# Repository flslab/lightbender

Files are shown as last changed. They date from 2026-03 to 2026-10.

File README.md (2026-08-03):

# LightBender
A LightBender is a form of FLS with an actuated rod as its lighting primitive.
A swarm of LightBenders illuminate graphics and animations visible to the naked eye.
When equipped with a cage, a LightBender facilitates safe, bare-hand interaction. 

Authors: Hamed Alimohammadzadeh(halimoha@usc.edu), Shuqin Zhu (shuqinzh@usc.edu), and Shahram Ghandeharizadeh (shahram@usc.edu)

Acknowledgments:  This research is supported in part by the National Science Foundation under Grant No. CMMI-2425754, CloudBank, and CloudLab. 

## Features

* Illuminations using a swarm of LightBenders, see below.
* Authoring tool in the form of a Blender add-on, see below and the instructions in the local [authoring](authoring/) directory.
* Bare-hand interaction with LightBenders, see below and the instructions in the local [Interaction](Interaction/) directory.
* Upload the video recording and log files generated by an illumination to a Google Drive for further analysis, see [orchestrator](orchestrator/) directory.
* Relative localization, see [relative-localization](https://github.com/flslab/fls-marker-localization.git).
* Log visualization tool, see [log visualizer web tool](https://flslab.github.io/fls-cf-log-visualizer/).

## Illumination
An artist may manipulate per-LED color and brightness, rod segment angles, and 3D position of one or more LightBenders to implement different visual effects. 

### LightBender Visual Effects

We support 7 visual effects today: Pulse, Color Cycle, Sparkle, Color Chase, Draw/Erase, Fold, and Fly-out/in.
These may be applied to arbitrary words and line drawings using the Blender add-on provided in the local [authoring](authoring/) directory.
Fold is a novel effect that utilizes the actuated rods of a swarm of LightBenders to transition lines to drawings and words.
The effects are highlighted by the following video clips:

- [Visual effects with ACM, LA, and NSF.](https://youtu.be/jwrJeGCwS_M)  
- [ACM Illumination.](https://youtu.be/oepzLSos4Xo)  
- [LA Illumination.](https://youtu.be/p_fx22tXJf8)  
- [NSF Illumination.](https://youtu.be/o2t5xLuE0Hw)

## Interaction
A cage provides safe bare-hand interactions with a LightBender, preventing users' hand and fingers from coming in contact with a LightBender's blades.  The provided software runs on the Raspberry Pi of a LightBender.  It enables the LightBender to monitor its own velocity to detect when a user engages or disegages.  This decentralized implementation enables multiple users to interact with different LightBenders simultaneously.  The following video shows Shahram and Shuqin interacting with a happy emoji.

- [Interaction with happy emoji.](https://youtu.be/_huysBvEuR4)
- [Vertical interaction with a LightBender.](https://youtu.be/ilh584zCPyQ)

Bare-hand interactions have diverse applications ranging from health-care to education and entertainment.  Our Blender add-on enables one or more users to adjust the position of LightBenders in an illumination using their bare-hands.  For a video demonstration, see [authoring](authoring/) directory.

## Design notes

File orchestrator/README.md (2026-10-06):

# Swarm Orchestrator

The Swarm Orchestrator manages the LightBender drone swarm. It handles executing SFL files, managing network communications, interacting with camera and radio nodes, downloading execution logs, and automatically uploading data after experiments.

## Setup

### 1. Install Dependencies
Ensure you have the required Python dependencies installed.
```bash
pip install -r requirements_orchestrator.txt
```

### 2. Configure the Swarm Manifest
The orchestrator relies on `swarm_manifest.yaml` to configure the network, drones, and mission files.

A sample template is provided as `swarm_manifest_sample.yaml`. To get started:
```bash
cp swarm_manifest_sample.yaml swarm_manifest.yaml
```

**Adjusting the manifest:**
Open `swarm_manifest.yaml` and update the following settings to match your environment:
- **`controller`**: Set your local machine's `ip`. You can define `mission_path` (e.g., `"SFL"`) and list out multiple `mission_files` to run sequentially.
- **`common.localizer_work_dir`**: Optional path to the marker-localization checkout on each drone; it defaults to `/home/fls/fls-marker-localization`. When that Git checkout exists, drone boot pulls it with a fast-forward-only update and runs its incremental high-rate release build before launching the controller.
- **`drones`**: Define the drones participating in the swarm. For each drone, make sure the `ip`, `uri`, hardware `type` (H or V), and `servo_offsets` match your actual hardware configurations.
- **`camera_node` / `radio_node`**: Provide the corresponding IP addresses and usernames for the remote nodes if you are using them for recording or CrazyRadio communication.
- **`marker_grid_node`**: Define the dedicated Raspberry Pi Zero W, its marker-grid checkout/virtual environment, grid JSON, UDP port, and GPIO levels. Set optional `hypergrid_tiles` to a list of `[i, j]` coordinates to light only those tiles' HyperGrid LEDs; omit it to light all HyperGrid tiles (an empty list lights none). The orchestrator validates and launches this node before it launches any drone. A drone that owns a MyGrid tile declares `marker_tile: [i, j]`.

The marker grid is deliberately not a drone peer. A drone requests a state
change over its existing ZMQ connection by sending
`{"id":"lb1","status":"MARKER_GRID_MODE","mode":"off"}`. The orchestrator
maps the drone ID to its manifest-owned tile and forwards an idempotent UDP
command to the grid. Modes are `blink`, `static`, and `off`; requests without a
drone target are reserved for orchestrator-wide lifecycle changes.
During cleanup, the orchestrator terminates the remote marker-grid controller;
its signal handler clears every LED channel before the process exits.

To test the physical marker grid without launching a mission, run
`python orchestrator.py --test-marker-grid`. The orchestrator turns on the
HyperGrid and all MyGrids, then prompts for Enter before turning each MyGrid
off and back on in snake order. Tile coordinates are `(i, j) = (x, y)`: tiles
with the same `i`, such as `(-1, -1)` and `(-1, 0)`, share an x row and are
adjacent along y. The controller is stopped when the test ends.

### 3. Uploader Setup
The orchestrator automatically uploads logs and experiment data (like recorded videos and drone logs) to Google Drive via the `uploader` module once a mission concludes.

Before running an experiment, you need to configure the uploader credentials:
1. A `.env.example` file is provided in the `uploader` directory. Copy it to create your `.env` file:
   ```bash
   cp uploader/.env.example uploader/.env
   ```
2. Edit `uploader/.env` and fill in:
   - `GOOGLE_CLIENT_SECRET`: Path to your downloaded OAuth client secret JSON file.
   - `GDRIVE_FOLDER_ID`: The ID of the shared Google Drive folder where data should be uploaded to.
   If you need to generate a new OAuth client secret JSON file, follow the instructions here: https://developers.google.com/workspace/guides/create-credentials

## Usage

Run the main script using Python. The orchestrator has a number of available execution modes.

```bash
python orchestrator.py [OPTIONS]
```

### Important Runtime Flags:
- **`--illumination`**: Run an illumination application mission.
- **`--interaction`**: Run an interaction application mission.
- **`--morphing`**: Run the mission with morphing algorithms enabled.
- **`--radio`**: Connect to drones over CrazyRadio (commands forwarded via the radio node).
- **`--ground`**: Perform a ground test without making the drones take off (useful for testing LED interactions or servos).
- **`--dark`**: Optimize camera parameters for recording in darkness.

### Control & Override Flags:
- **`--off`**: Cleanly power off / shut down all Raspberry Pis on the drones.
- **`--kill`**: Terminate the active Python controller processes on all drones.
- **`--skip-record`**: Run the mission without triggering the camera node.
- **`--record`**: Run the camera script strictly to record (no drone operation).
- **`--skip-confirm`**: Bypass manual confirmation prompts during the initialization sequence.

### Example Experiment

Running a standard illumination mission:
```bash
python orchestrator.py --illumination
```
When executed, the orchestrator will:
1. Parse the configurations and mission files from `swarm_manifest.yaml`.
2. Connect to the drones and issue restart commands.
3. Automatically launch the remote scripts and await "READY" payloads.
4. Prompt you (if not skipped) to launch the swarm.
5. Manage flight state logic and await "LANDED" confirmations.
6. Gather logs locally and trigger the `uploader` to save them seamlessly to Google Drive.

## Mock Blender Flow

To emulate an illumination launch without booting the real swarm, run:

```bash
python mock_orchestrator.py
```

This mock client connects to the Blender add-on's swarm monitor socket on `127.0.0.1:5598`, sends the same newline-delimited JSON status messages as the real orchestrator, and pauses before each message group so you can confirm the next step from the CLI.

Helpful flags:
- `--drone-id lb1 --drone-id lb2`: limit the mock run to specific drones.
- `--manifest path/to/swarm_manifest.yaml`: use a different manifest.
- `--message-delay 0.0`: send each group immediately with no spacing between messages.
- `--auto-cleanup-on-stop`: if Blender sends `stop`, automatically follow with `logs_fetched` and `all_stopped`.

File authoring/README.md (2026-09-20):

# LightBender Authoring

This directory contains the tools for designing, animating, and visualizing LightBender drone swarms. The primary authoring interface is a Blender add-on that enables an artist to place LightBenders in 3D space, animate LEDs and servos, and export an SFL (mission YAML) file for physical illumination using LightBenders and the orchestrator.  The add-on supports a novel edit mode that enables the artist to interact with the LightBenders and adjust their location using their bare hand. 

Authors: Hamed Alimohammadzadeh(halimoha@usc.edu), Shuqin Zhu (shuqinzh@usc.edu), and Shahram Ghandeharizadeh (shahram@usc.edu)

---

## Edit Mode Using Bare-Hand Interactions

We support bare-hand interactions with LightBenders to edit graphics.  Multiple users may adjust the position of LightBenders using their bare hand simultaneously.  Our implementation of the Blender add-on updates the data in real-time.  The following video shows the workflow of a bare-hand interaction in support of edit mode. 

- [Blender add-on in edit mode with bare-hand interactions.](https://youtu.be/_I6qcD0NoYM)

## LightBender Visual Effects

LightBender visual effects for different illuminations:

- [Visual effects with ACM, LA, and NSF.](https://youtu.be/jwrJeGCwS_M)  
- [ACM Illumination.](https://youtu.be/oepzLSos4Xo)  
- [LA Illumination.](https://youtu.be/p_fx22tXJf8)  
- [NSF Illumination.](https://youtu.be/o2t5xLuE0Hw)  

## Blender Add-On

LightBender Swarm Animator

**LightBender Swarm Animator** (`blender_addon.py`) is a Blender 3.0+ add-on located in `View3D > Sidebar > LightBender`. It provides a full GUI workflow for:

- **LightBender placement** — add Type H/V rods, semicircle, or ring light elements with correct geometry and LED strips
- **Generative layouts** — automatically place LightBenders along SVG strokes using Vertex First Greedy (VFG) or Set Cover (SC) placement algorithms
- **LED animation** — define LED pointers (split points + color expressions) and apply global color expressions
- **Global LED effects** — apply procedural animation presets (Static Color, Blinking, Sparkle, Rainbow Wheel, Color Chase, Pulse, Color Cycle) to all or selected LightBenders
- **Draw/Erase effect** — sequence or simultaneously animate LightBenders writing strokes, with per-drone direction control and keyframe reversal
- **Fold effect** — keyframe LightBenders unfolding from a straight lit state into their target pose
- **Fly-In/Fly-Out effect** — generate exploded-assembly fly-in sequences
- **Morph** — transition the swarm from the current SVG layout to a new SVG shape
- **Position errors & drift** — inject random positional noise or continuous drift for simulation realism
- **Stagger** — stagger LightBender positions based on camera perspective to avoid downwash
- **Live swarm monitoring** — real-time per-drone status and battery voltage in list or grid view with filtering
- **Export & launch** — write the full animation to YAML and optionally launch the orchestrator or an interactive bare-hand editing session directly

### Installing the Add-On

1. In Blender, go to **Edit > Preferences > Add-ons > Install…**, select `blender_addon.py`, and enable the **LightBender Swarm Animator** add-on.

2. The panel will appear in the **3D Viewport sidebar** under the **LightBender** tab (`N` key to open).

3. In **Edit > Preferences > Add-ons**, find **LightBender Swarm Animator** and set the **Repository Directory** to the absolute path of your local clone. The path is saved permanently in Blender's user preferences — you only need to set it once.

The Set Cover policy can use either the built-in branch-and-bound solver or
Gurobi. To use Gurobi, install `gurobipy` in the external Python environment
used by the add-on and configure a valid Gurobi license. Other placement
policies and the built-in solver do not import or require Gurobi at runtime.

---

## Panel Reference

The sidebar is organized into one root panel and five collapsible sub-panels.

---

### LightBender Controls

The root panel. Always visible.

#### Add LightBender

Select a **Light Element Type** from the drop-down, then click **Create**:

| Type | Description |
|---|---|
| **Type H (Rod)** | Two-segment rod. Segment 1 spans 0–180°, Segment 2 spans 180–360°. |
| **Type V (Rod)** | Two-segment rod rotated 90°. Segment 1 spans 90–270°, Segment 2 spans 270–450°. |
| **Semicircle H** | Single-segment arc, 0–180°. One servo. |
| **Semicircle V** | Single-segment arc, 90–270°. One servo. |
| **Ring** | Full circle, no servo actuation. |

When **Ring** is selected, a **Ring Radius** (m) field appears before the Create button.

Click **Delete All LightBenders** to clear all LightBenders and their associated components from the active viewport.

#### Selected LightBender Controls

These controls appear when a LightBender object (`lb*`) is the active selection.

**Servo Angles**

- **Angle 1** (or **Arc Angle** for Semicircle types) — servo 1 angle in degrees.
- **Angle 2** — servo 2 angle in degrees (hidden for Semicircle types).
- Ring types show a "No Actuation" label; servo fields are suppressed.

**LED Configuration**

- **Mode** — choose between two per-drone LED modes:
  - **Single Expression** — one Python formula evaluated per LED. Available variables: `i` (LED index), `t` (time in seconds), `N` (total number of LEDs), `math`, and `random`. Example: `[255, 255, 255] if i < t*10 else [0, 0, 0]`.
  - **Pointers** — define colored segments using a base color and a list of split-point pointers. Each pointer has a position value and a color expression; LEDs before a pointer inherit the previous segment's color.
    - **Base Color (Start)** — color expression applied before the first pointer.
    - **Pointers list** — add/remove pointers with `+`/`−`. Each row shows the split position and the color to the right of that split.

- **Test/Update LEDs** — re-evaluates all LED formulas and refreshes viewport colors immediately (useful after editing formulas without scrubbing the timeline).

---

### Generative Layouts

Automates swarm placement from an SVG file or recreates layouts and animations by importing YAML mission files.

At the very top of this panel, there is a shared **Swarm Manifest** path field. When specified, both the SVG Transform and Import Mission tools will use it to match drone IDs and resolve their hardware types.

#### Import Mission YAML

Recreates the LightBenders, servo angles, LED configurations (expressions or pointers), and keyframe animations from a previously exported YAML mission file.

| Field | Description |
|---|---|
| **Mission YAML** | Path to the source mission YAML file to import. |

Click **Import Mission** to parse the YAML and build the animation in the viewport. The button is disabled until a file is selected.

#### SVG Transform and Place

Reads an SVG shape and places LightBenders along the shape's strokes using available LightBenders in the manifest. If there are not enough LightBenders in the manifest, it will insert additional LightBenders labeld as extra. 

| Field | Description |
|---|---|
| **SVG File** | Path to the source SVG file. |
| **Max Width / Max Height** | Bounding box (m) to scale the SVG layout into. |
| **Center X / Center Z** | World-space coordinates for the layout center. |
| **Placement Policy** | **VFG** or **Set Cover** — algorithm used to place drones along the shape's strokes. |
| **Set Cover Solver** | Shown for Set Cover. Choose dependency-free **Built-in B&B** or the lexicographic **Gurobi** MIP backend. |
| **LED Color** | Python RGB list (e.g. `[255, 0, 0]`) applied to all placed drones. |

Click **Transform and Place** to run the placement. The button is disabled until an SVG file is selected.

---

### Automated Animations

Contains five keyframe-generation tools.

#### Morph

Transitions the swarm from its current SVG-based layout to a second shape.

| Field | Description |
|---|---|
| **Shape 2 SVG** | Path to the target SVG file. |
| **Hold 1 (s)** | Time to hold the initial shape before moving. |
| **Morph (s)** | Duration of the transition between shapes. |
| **Hold 2 (s)** | Time to hold the final shape after arriving. |

Click **Generate Morph** to insert keyframes.

#### Fold

Animates all selected LightBenders unfolding from a straight, fully-lit state into their current posed angles.

| Field | Description |
|---|---|
| **Fold Angle (deg)** | Servo-1 angle for the straight state (Servo 2 = Fold Angle + 180°). TYPE_V offsets this by 90°. |
| **Hold (s)** | Duration of the straight state before folding. |
| **Transition (s)** | Duration of the fold-in motion. |
| **Align** | Snap all LBs to the swarm centroid along the selected axis (X/Y/Z) during the straight state. |
| **Distribute** | Evenly space all LBs along the selected axis (X/Y/Z) during the straight state. |
| **Equalize Size** | Scale each LB's LED pointer range by its camera distance so all rods appear the same on-screen length. |
| **Resolve Overlaps** | After positioning, stretch LB positions along the selected axis until the minimum inter-LB gap equals **Min Spacing**. |
| **Min Spacing (m)** | Minimum allowed distance between any two LBs when overlap resolution is active. |

Click **Generate Fold** to write keyframes; **Trash** icon clears them.

#### Draw/Erase

Sequences LightBenders to illuminate progressively, simulating a stroke being drawn and then erased.

**Groups list** — each group represents one stroke or letter. Groups can be Sequential (drawn one after the other) or Simultaneous (drawn in parallel). Use `+`/`−` to add/remove groups; click a group to manage its members.

**LightBenders in \<group\>** — ordered list of drones assigned to the active group. Use `+`/`−` to add/remove drones (adds the current viewport selection); arrow buttons reorder them.

**Settings:**

| Field | Description |
|---|---|
| **Draw Speed (LEDs/s)** | Rate at which LEDs illuminate during the draw pass. |
| **Erase Speed (LEDs/s)** | Rate at which LEDs turn off during the erase pass. |
| **Hold Time (s)** | Pause between the end of draw and the start of erase. |
| **Overlap Next (%)** | How much the next group's draw begins before the current group finishes (0 = fully sequential, 100 = fully overlapping). |
| **Draw RGB** | Color used during the draw pass (Python RGB list). |
| **Erase RGB** | Color used during the erase pass / background color (Python RGB list). |

Click **Generate Draw/Erase** to write keyframes; **Trash** icon clears them.

#### Fly-In / Fly-Out

Generates an exploded-assembly animation: drones fly in from off-screen positions to their targets, hold, then fly back out.

| Field | Description |
|---|---|
| **Ref Distance (m)** | Distance of the explosion reference point behind the centroid. |
| **Min/Max X, Y, Z (m)** | World-space bounding box from which start positions are sampled. |
| **Outward Duration (s)** | Time for drones to travel from their targets to the exploded positions. |
| **Hold Duration (s)** | Time drones pause at the exploded positions. |
| **Inward Duration (s)** | Time for drones to fly from the exploded positions back to their targets. |

Click **Generate Fly-In/Fly-Out** to write keyframes; **Trash** icon clears them.

#### Flight Attitude

Generates yaw-relative roll and pitch for the selected LightBenders from their
animated positions. The operator estimates acceleration over the position-keyed
frame range, smooths it, and writes per-frame roll/pitch keys while preserving
existing yaw animation.

| Field | Description |
|---|---|
| **Max Tilt** | Maximum combined roll/pitch angle produced by horizontal acceleration. |
| **Smoothing** | Number of frames on either side used to smooth acceleration and braking. Higher values produce slower, softer banking. |

Click **Apply to Selected** after selecting one or more position-animated
LightBenders. Applying replaces any existing roll and pitch curves; location
and yaw keys are left unchanged.

---

### Global LED Effects

Applies a procedural LED animation preset to all selected (or all) LightBenders in the scene.

**Preset** — choose from seven animation presets:

| Preset | Description |
|---|---|
| **Static Color** | Single, unchanging color. |
| **Global Blinking** | All LEDs cycle through the color list simultaneously. |
| **Random Sparkle** | Each LED randomly flickers independently. Controlled by **Sparkle Threshold**. |
| **Rainbow Wheel** | A moving rainbow gradient sweeps across LEDs over time. |
| **Color Chase** | A moving block of color travels along the LED strip. |
| **Pulse** | Brightness smoothly pulses in and out. |
| **Color Cycle** | Smoothly blends between two colors using a sin/cos oscillation. |

**Color list** — add/remove colors with `+`/`−`. Click **Load Preset Colors** to populate the list with sensible defaults for the selected preset.

| Field | Description |
|---|---|
| **Speed Multiplier** | Scales the animation speed for all presets. |
| **Sparkle Threshold** | (Sparkle only) Probability above which a LED shows the sparkle color. 0 = always on, 1 = never. |

Click **Apply to Selected** to write the expression only to the selected LightBenders, or **Apply to All** to target every LightBender in the scene.

---

### Physics & Simulation

Injects positional noise and staggers LightBender positions based on camera perspective to avoid downwash and overlaps.

#### Error & Drift Simulators

**Static Error (YZ Plane)**

Randomly offsets each LightBender to simulate real-world positioning inaccuracy.

| Field | Description |
|---|---|
| **Error Distance (m)** | Maximum random offset applied to each drone. |

Click **Apply Static Error** to offset positions; **Reset Static** to undo.

**Dynamic Drift (XYZ)**

Applies a smooth, sinusoidal drift to each LightBender's position over time, simulating hovering instability.

| Field | Description |
|---|---|
| **Max Drift XY (m)** | Maximum drift amplitude in the X and Y axes. |
| **Max Drift Z (m)** | Maximum drift amplitude in the Z axis. |
| **Wave Scale (Slower=Higher)** | Noise frequency scale; higher values produce slower, wider drift. |

Click **Apply Drift** to generate drift keyframes; **Reset Drift** to remove them.

#### Stagger

Resolves downwash and overlap conflicts by shifting LightBenders toward or away from the camera.

| Field | Description |
|---|---|
| **Overlap Threshold (m)** | Distance below which two drones are considered overlapping. |
| **Downwash Threshold (m)** | Horizontal distance below which a drone is in the downwash of an upper drone. |
| **Selection Method** | Algorithm for choosing which Lightbenders to stagger: **Greedy Max Degree**, **Greedy Top Z**, **Greedy Bottom Z**, **Brute Force**, or **Random**. |
| **Resolution Order** | Priority for resolving conflicts: **Max Degree**, **Top Z**, **Bottom Z**, or **Random**. |
| **Trajectory Type** | **Line of Sight** — move along the camera ray; **Global** — move along the global centroid. |
| **Move Direction** | **Away** from camera, **Towards** camera, or **Hybrid** (choose the direction that minimizes distance). |

Click **Stagger** to apply; **Reset Stagger** to restore original positions.

---

### Mission Export

Writes the animation to an SFL (YAML) file and optionally launches the orchestrator.

#### Export Config

| Field | Description |
|---|---|
| **Mission Name** | Base name used for the output SFL file (defaults to the Blender scene name). |
| **Dark Room** | Enable dark-room mode in the generated mission. |

#### Mode

Toggle between two export/illuminate modes:

**Illumination** 

| Field | Description |
|---|---|
| **Export Keyframes Only** | When enabled, only keyframe times are exported (variable `dt` per waypoint). When disabled, waypoints are sampled at a fixed rate. |
| **Export Rate (Hz)** | Sampling frequency when not in keyframe-only mode. |

Buttons:
- **Export YAML** — write the mission file to `orchestrator/SFL/<mission_name>.yaml`.
- **Illuminate** — export and immediately launch the orchestrator in a new terminal tab.
- **Confirm Launch** — enabled once all drones report `ready`; arms the swarm and begins the mission.
- **Stop** — commands all drones to land and waits for confirmation.

**Interaction**

| Field | Description |
|---|---|
| **S_D (mm/s)** | Speed threshold exported as `delta_v` (m/s) in the interaction YAML. |
| **Grace Time (s)** | Delay before the interaction controller begins accepting commands. |
| **Interaction Duration (s)** | Maximum duration of the interactive editing session. |

Buttons mirror Illumination mode, plus:
- **Edit** — opens a bare-hand editing session.
- **Finish Edit** — closes the editing session and returns drones to hover.

#### LightBender Status

Live swarm monitor, nested inside Mission Export. Updated in real time while the orchestrator is running.

**View Mode** — switch between **List** and **Grid** displays:

- **List** — shows all drones in a scrollable list with ID, status, and battery voltage. Filter controls:
  - **Status filter** — show All, Idle, Booting, Ready, or Landed drones.
  - **Voltage filter** — show All, Charged (≥ threshold), or Discharged (< threshold) drones.
  - **Battery Threshold (V)** — voltage cutoff for the charged/discharged filter (default 3.9 V).
  - Clicking a list entry selects the corresponding LightBender object in the 3D viewport.

- **Grid** — compact tile view with one button per drone labeled with its numeric ID. Tile color indicates status: gray = idle, yellow = booting, green = ready, blue = landed, red = error. Clicking a tile selects the drone in the 3D viewport.

---

## LB Author, CLI End-to-End Pipeline

For users who want to run the full authoring pipeline from the command line without using the graphical interface, the `lb_author.sh` script automates the complete flow from SVG parsing to spatial staggering and orchestrator invocation.

### Pipeline Steps

The script runs the following steps sequentially, ensuring the input file of each script is available before proceeding:
1. **Transform (`transform.py`)**: Converts an SVG file into a scaled 3D graph.
2. **Place (`place.py`)**: Maps the 3D graph onto a tentative layout of LightBenders.
3. **Stagger/Deconflict (`deconflict.py`)**: Checks for overlap and downwash conflicts and repositions drones to resolve them.
4. **Convert to SFL (`convert_to_mission.py`)**: Converts the staggered layout into an SFL mission file.
5. **Orchestrator (`orchestrator.py`)**: (Optional) Triggers the swarm orchestrator to illuminate the deconflicted mission layout.

### Setup Python Virtual Environment

If you have not already, go to the lightbender/ directory and create a Python virtual environment:

```bash
cd lightbender/
python3 -m venv env
source env/bin/activate
pip install -r authoring/requirements.txt
```

After the first time you only need to activate the virtual environment:

```bash
source env/bin/activate
```

### Usage

```bash
bash authoring/lb_author.sh [options] <input_file.svg>
```

#### Options

- `--no-viz`: Disables all step-by-step graphical 2D and 3D visualizers (e.g., matplotlib popups), allowing the entire script to run silently in headless/CLI environments.
- `--illuminate`: Automatically triggers the swarm orchestrator (`orchestrator.py`) at the end of the pipeline to launch and execute the generated mission layout.

#### Examples
To run the complete pipeline with visualizers:
```bash
bash authoring/lb_author.sh authoring/svg/s.svg
```
**Note:** To proceed to the next step, you need to close the plot windows.

To run the complete pipeline silently without visualizers:
```bash
bash authoring/lb_author.sh --no-viz authoring/svg/s.svg
```

To run the pipeline and immediately launch the orchestrator:
```bash
bash authoring/lb_author.sh --illuminate authoring/svg/s.svg
```

Optianly you can visualize the final SFL file using the following command:
```bash
python analysis/rmse_all.py --yaml orchestrator/SFL/lb_author_mission.yaml --lit-only
```

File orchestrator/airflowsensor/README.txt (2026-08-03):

This is Version 0 of the software for airflow sensor.  The python file in this directory is a standalone software executed on a RPi.  

Hardware:  
- Manufacturer:  Sensirion AG
- Model Number:  SEK-SDP31
- Description:   Digital Pressure Sensor Evaluation Kit.
- URL:  https://www.digikey.com/en/products/detail/sensirion-ag/SEK-SDP31/16517716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

3D Printed Parts: 
- Mounting of the airflow sensor to the rod for conducting experiments:
  * 3D printable files are Flow_element_grip.3mf and Rod_grip.3mf
  * 3D fusion files are FlowElement_grip.f3d - unfortunately, the fusion file for the other one is lost. 
- Prior to the arrival of the sensor, we 3D printed the part in order to setup the experiments with LightBenders.  The AutoCAD Fusion version of these files is ./

Software:  Custom built python at USC.

Requirements:
1. Enable I2C on RPi by running sudo raspi-config in the terminal.  Navigate to Interface Options, select I2C, choose Yes to enable it and automatically load kernel modules, and then reboot the system.  
2. Update ../orchestrator.py with the updated logic in ./orchestrator.py. 
3. Copy the manifest file (./swarm_manifest_sample.yaml) that describes the airflow sensor node in the Orchestrator directory.  
4. Run the updated Orchestrator with the additional flag, using the following command:  Python3 orchestrator.py --illumination --sensor

Output:
1. The revised Orchestrator generates log records based on Experiments 1 to 4 in the Google Slide. 

Experiments conducted using this software in the context of four different experiments are available in the following Google Slide:  https://docs.google.com/presentation/d/1wRDwtCE3NHDeBA4fOQYP56STGkDCzMYEMwvgELqPWFg/edit?usp=sharing

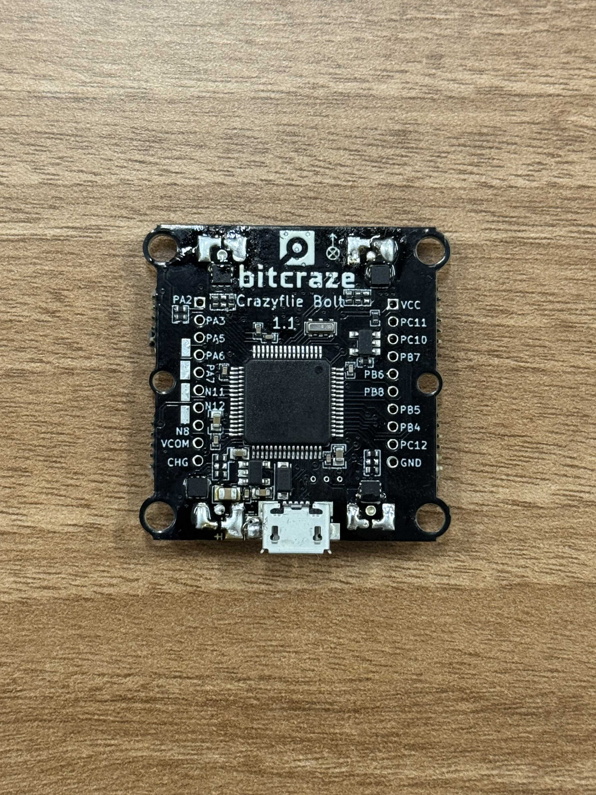
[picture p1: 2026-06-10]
docs/img/fc_down.jpeg

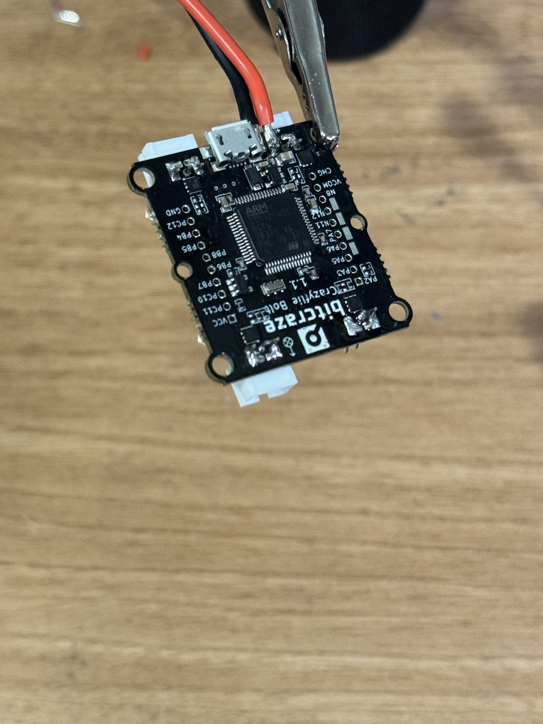
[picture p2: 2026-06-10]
docs/img/fc_power.jpeg

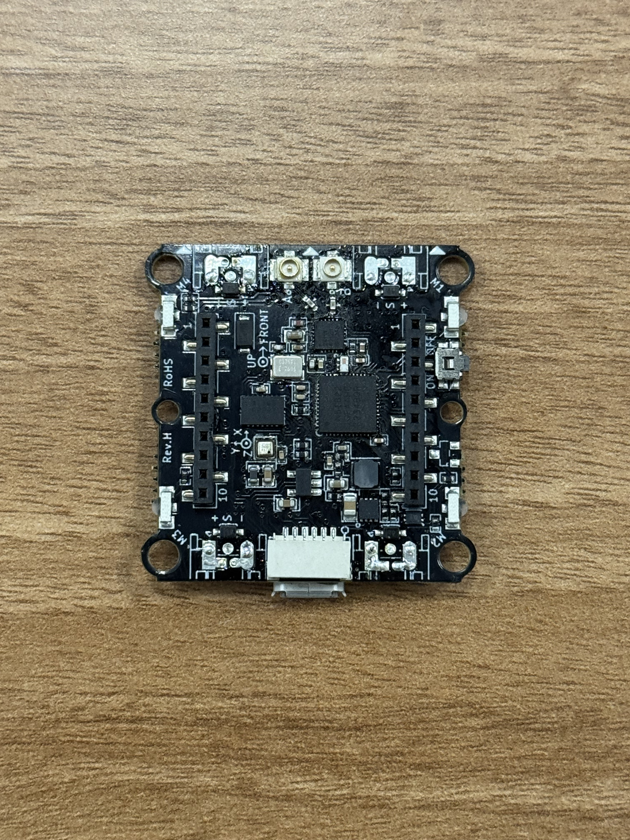
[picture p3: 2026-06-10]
docs/img/fc_up.jpeg

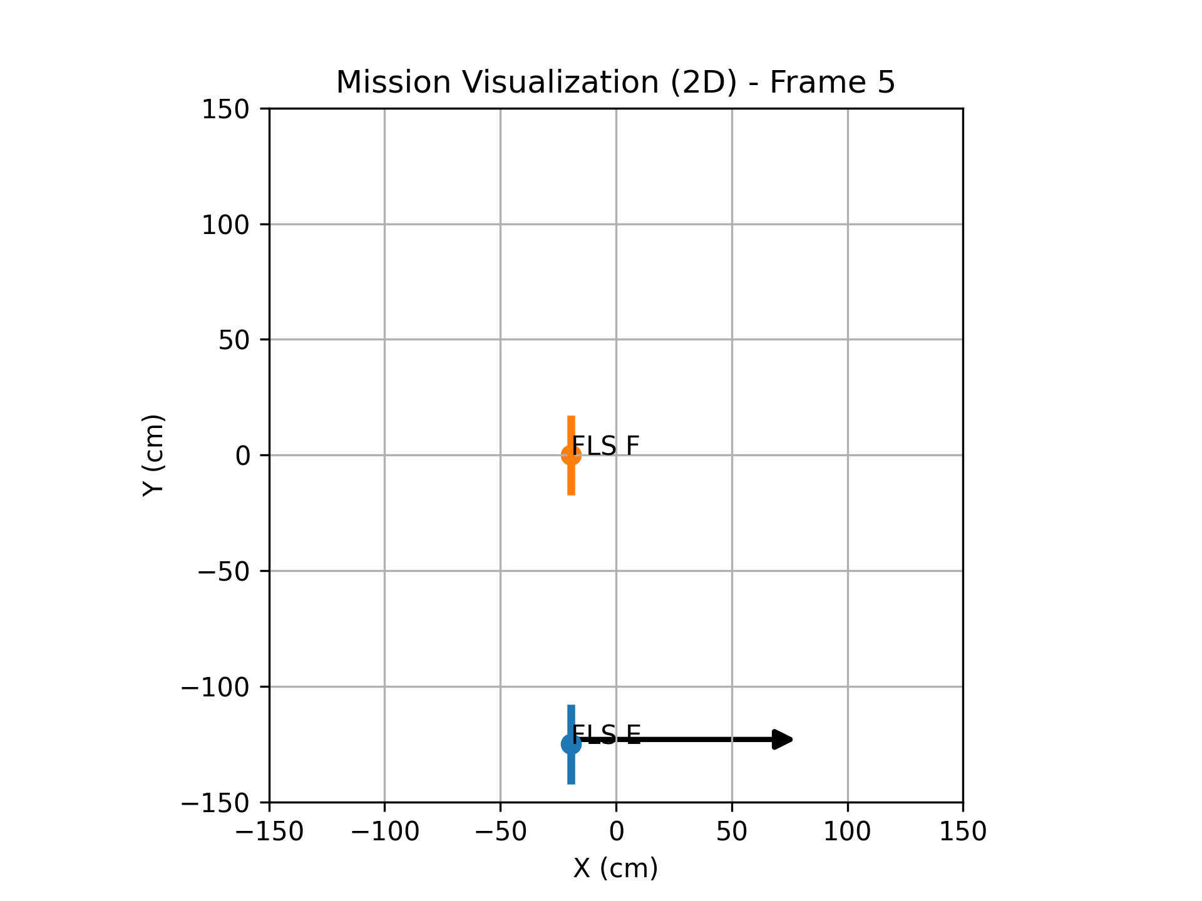
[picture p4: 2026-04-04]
morphing-orchestrator/mission_visualizations/mission_frame_5.png

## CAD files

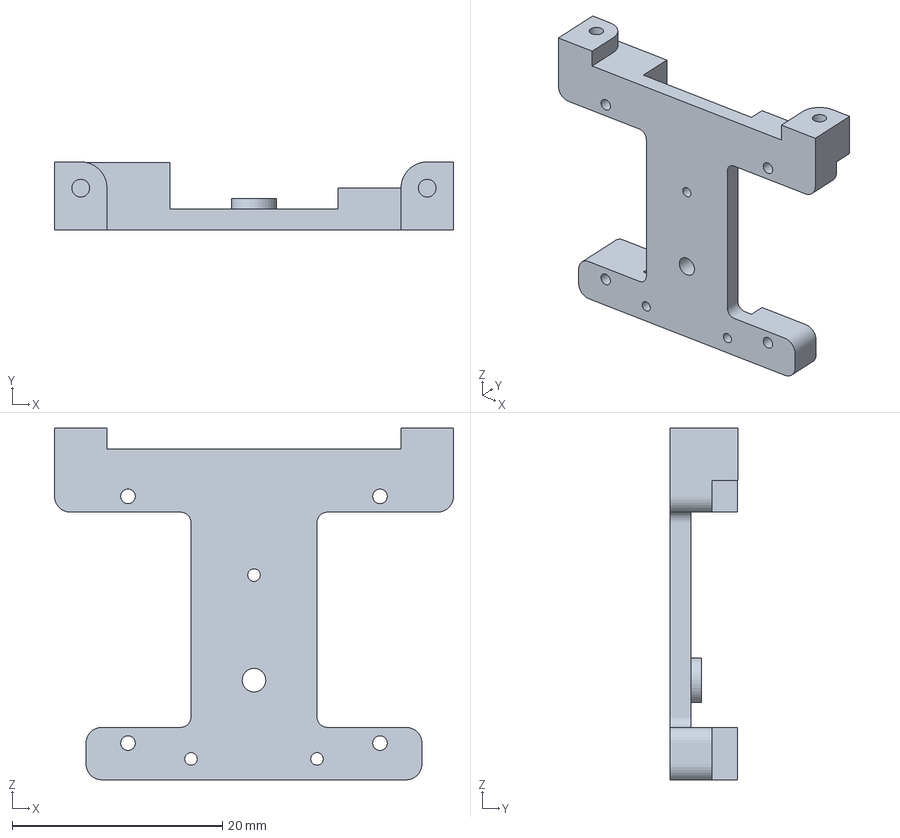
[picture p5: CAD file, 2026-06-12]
3d/linear/servo_case.3mf
38.0 x 6.50 x 33.5 mm

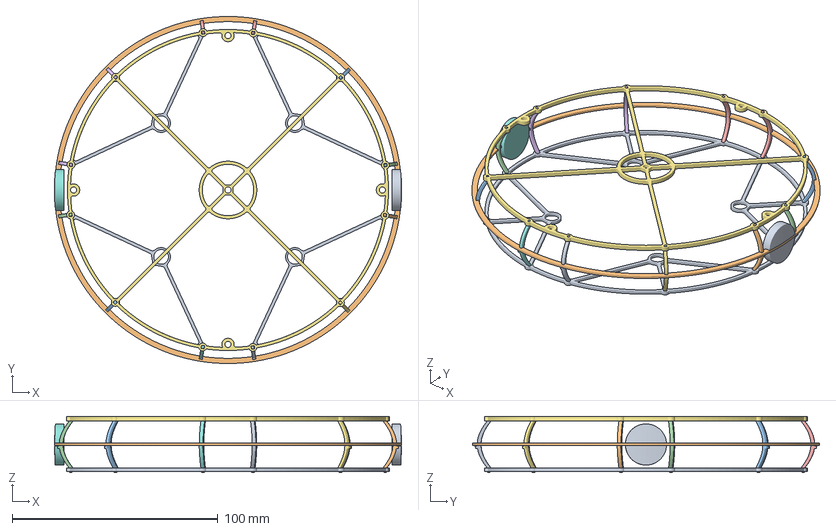
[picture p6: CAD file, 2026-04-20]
Interaction/Cage_Design/Crazyflie_Interaction_Cage.3mf
168.8 x 168.6 x 27.4 mm

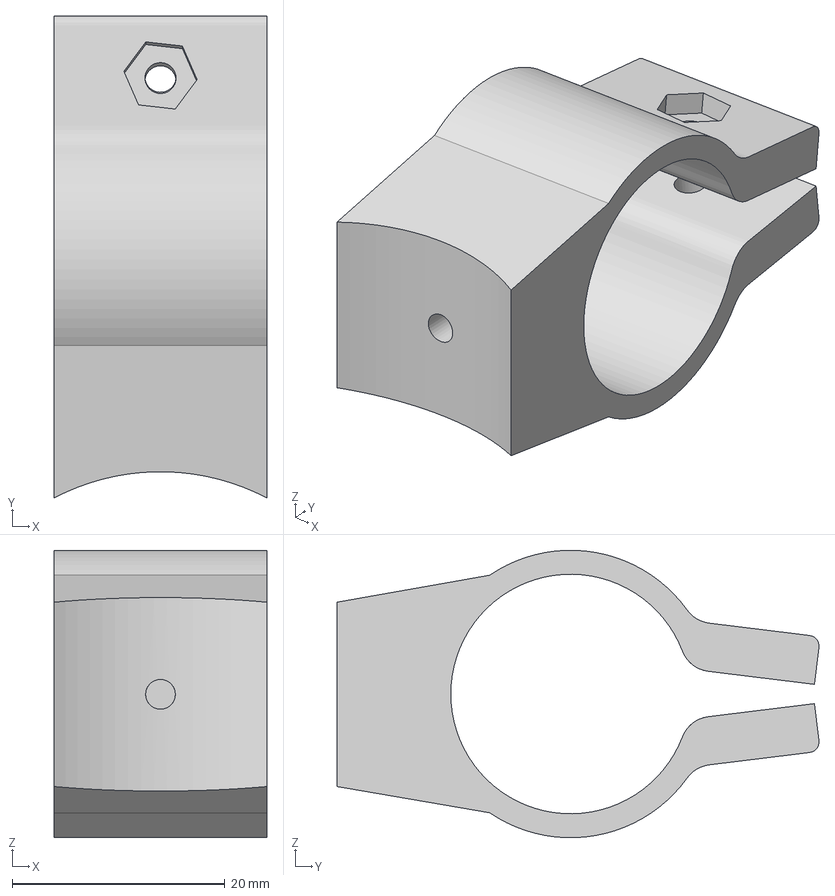
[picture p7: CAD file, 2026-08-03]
orchestrator/airflowsensor/Flow_element_grip.3mf
20.0 x 45.3 x 27.0 mm

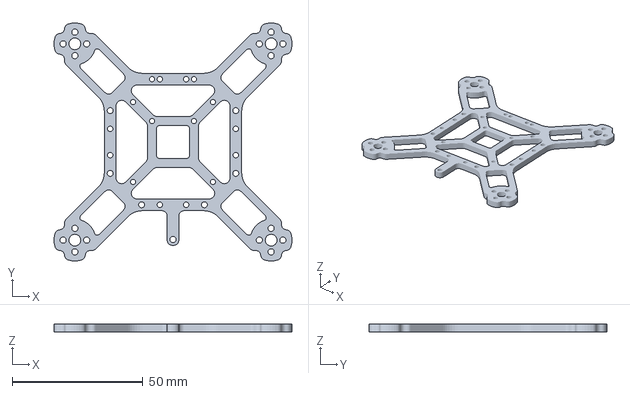
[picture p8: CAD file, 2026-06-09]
3d/linear/frame.3mf
91.0 x 91.0 x 3.00 mm

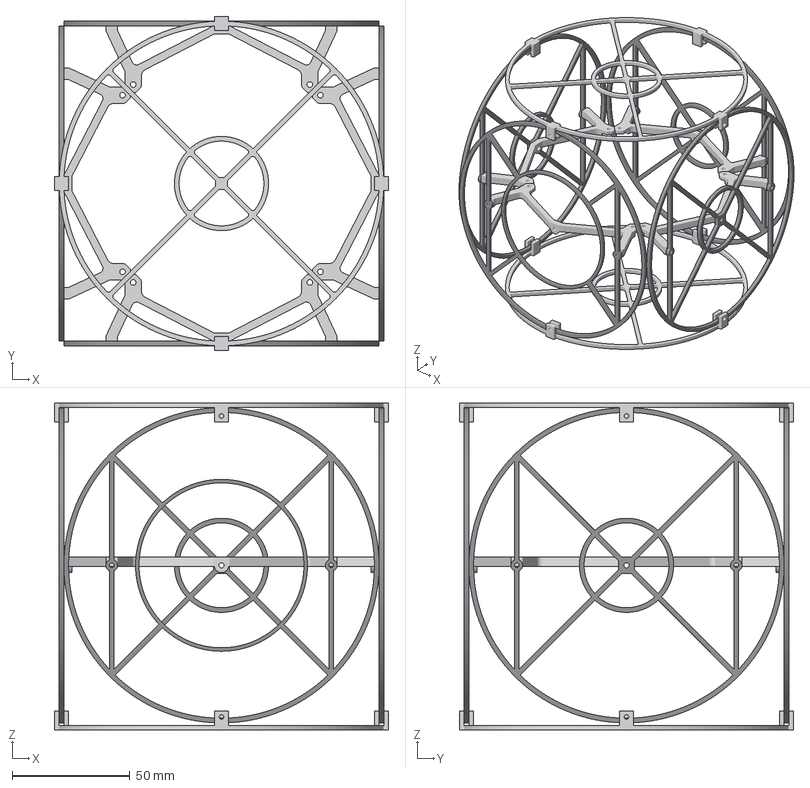
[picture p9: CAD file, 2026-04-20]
Interaction/Cage_Design/LightBender_Interaction_Cage.3mf
141.8 x 141.8 x 138.8 mm

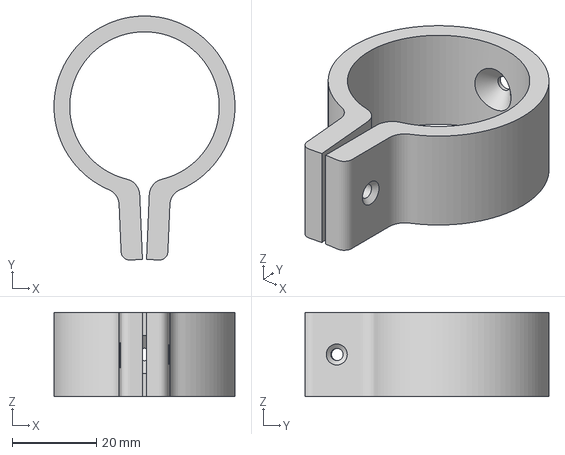
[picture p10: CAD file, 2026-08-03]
orchestrator/airflowsensor/Rod_grip.3mf
43.0 x 57.9 x 20.0 mm

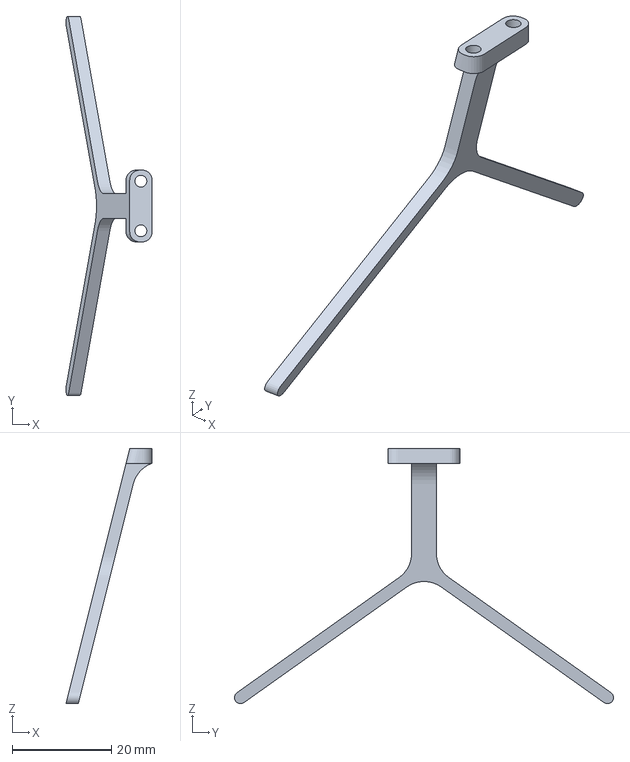
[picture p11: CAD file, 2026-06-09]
3d/linear/landing_gear.3mf
17.4 x 76.4 x 51.5 mm

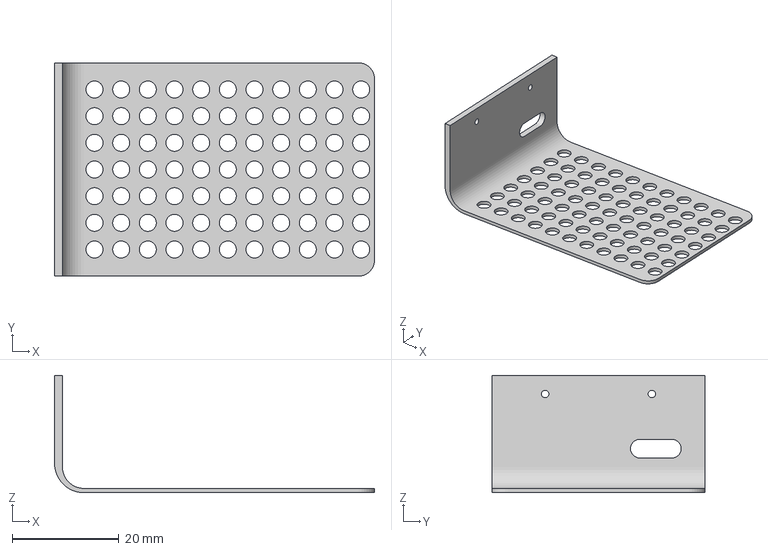
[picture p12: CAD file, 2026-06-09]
3d/linear/rpi_cover.3mf
60.0 x 40.0 x 22.0 mm

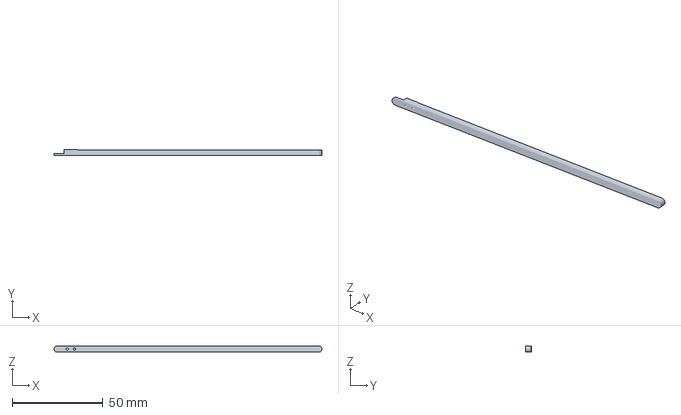
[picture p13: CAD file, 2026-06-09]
3d/linear/tube_segment.3mf
147.5 x 3.20 x 3.50 mm

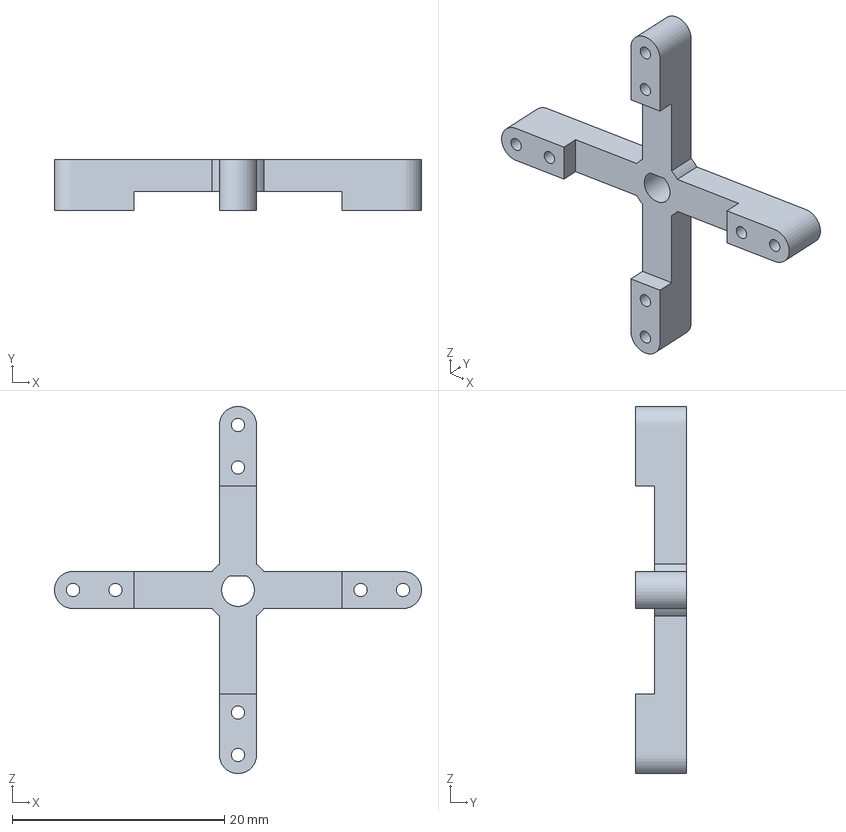
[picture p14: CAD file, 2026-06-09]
3d/linear/tube_joint.3mf
34.6 x 4.80 x 34.6 mm

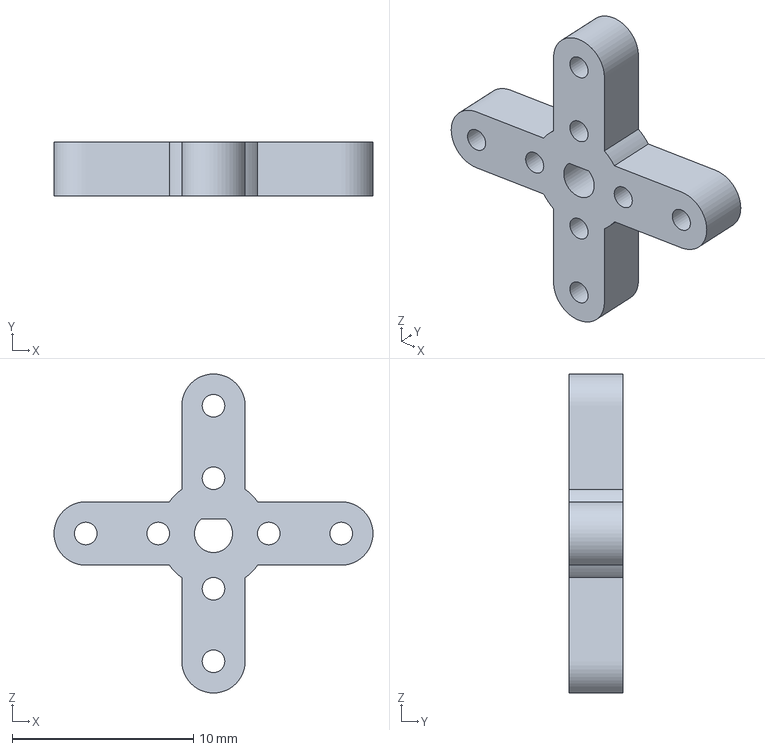
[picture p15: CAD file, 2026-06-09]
3d/linear/rod_joint.3mf
17.6 x 3.00 x 17.6 mm

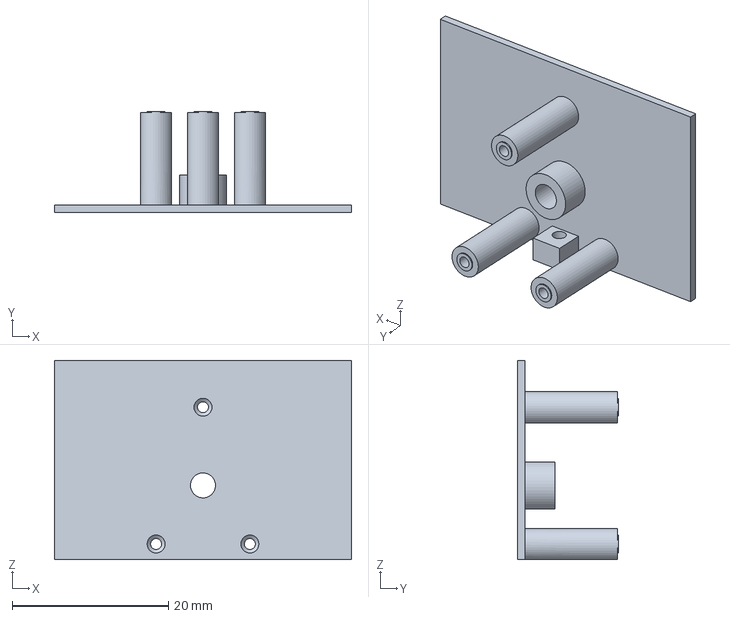
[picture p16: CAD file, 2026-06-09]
3d/linear/gearbox_case.3mf
38.0 x 12.9 x 25.5 mm

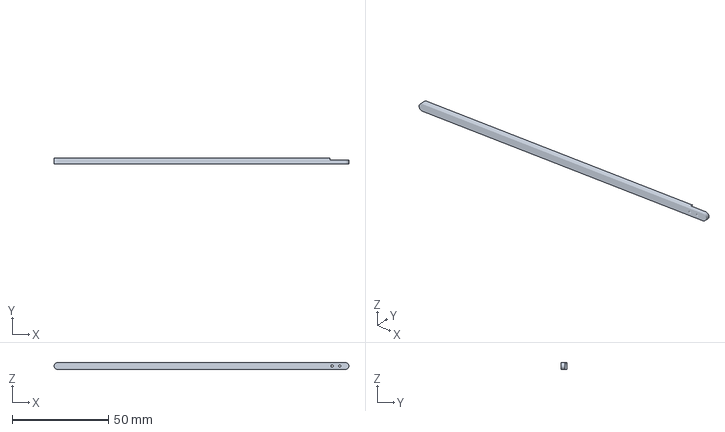
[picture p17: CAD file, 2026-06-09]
3d/linear/rod_segment.3mf
153.5 x 3.00 x 3.50 mm

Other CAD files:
orchestrator/airflowsensor/FlowElement_grip.f3d

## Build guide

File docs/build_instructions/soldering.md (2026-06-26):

# Soldering and Assembling

Required tools:

1. Soldering iron
2. Screwdriver set
3. Wire cutters and strippers
4. Pliers
5. Desoldering wick

Required parts:

1. Motors x 4
2. ESC x 1
3. CF Bolt Flight controller x 1
4. Power wires x 1
5. Capacitor x 1
6. Mulex wire with male connector x 1
7. Mulex wire with female connector x 1
8. Servos x 2
9. LED strips
10. Magnet wires
11. Power regulator x 1
12. Raspberry Pi Baseboard x 1

## Prepration:

Step 1: Unbox the motors and screw them to the frame. Use the 5mm screws (the meduim size in the package).
When mounting the motors, make sure the wires from the motor are facing towards the center of the frame.
Cut the wires from motor to desired length.

Step 2: Cut the mulex wires as shown below.

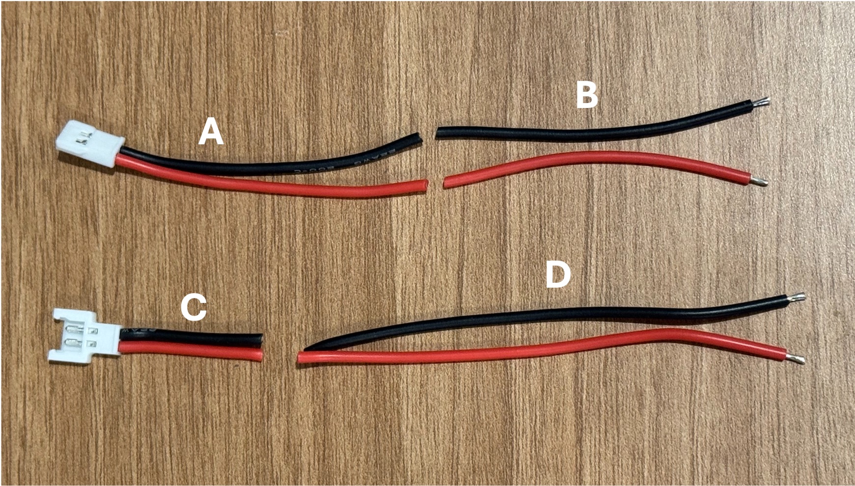
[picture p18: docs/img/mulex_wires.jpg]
Cutting the mulex wires.


Step 3: Cut the XT30 power wires from the ESC to desired length(around 2 inch or 5 cm).

Step 4: Cut 4 peice of wires for motor signal wires (around 1.5-2 inch or 4-5 cm).

Step 5: Cut 3 pieces of wires making a USB cable (around 2.5 inch or 6 cm)

Step 6: Cut the connectors of the servos.

Step 7: Cut 5 pieces of magnet wires around 20 cm each.

Step 8: Strip the tip of all prepared wires in Steps 1 to 7 and put solder on them. For magnet wires use a soldering iron and solder to melt the coating.

Step 9: Cut two strips of 24 and 26 LEDs from LED strip. When cutting make sure you cut from the lines between the LEDs such that each LED has 3 connection points. One ground (GND), one data (DI), and one power (VCC/5V).

Step 10: Remove the 3-pin connectors from the flight controller. First remove the plastic housing gently using a plier, and then remove the pins using a soldering iron.

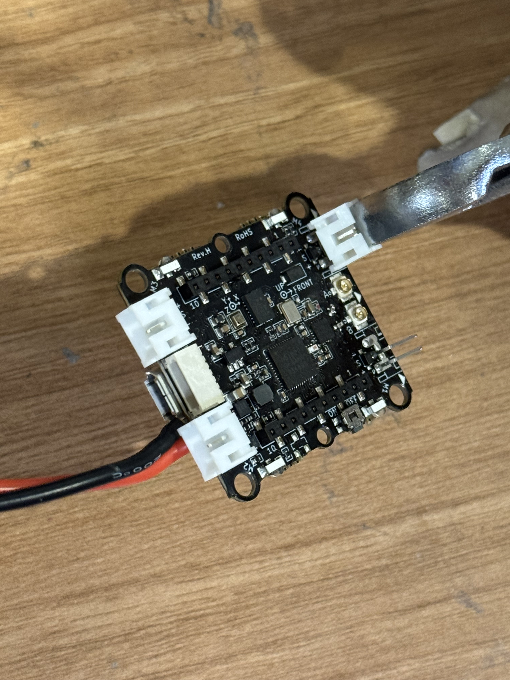
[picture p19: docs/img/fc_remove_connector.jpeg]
Removing plastic housings.


Step 11: Desolder the power wires from the FC.

## ESC and FC Assembly

Step 12: Solder wire B to the FC.

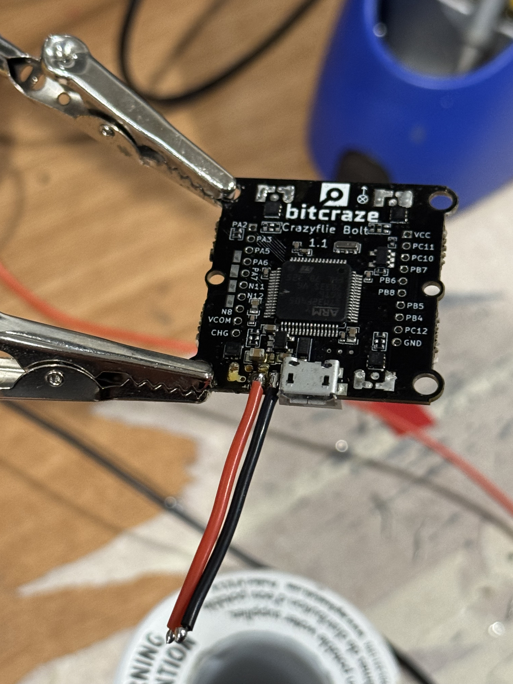
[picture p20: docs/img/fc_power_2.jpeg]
Soldering power cables to the FC.


Step 13: Solder the capacitor and XT30 power wires to the bottom side of the ESC.

Step 14: Solder the mulex wire with the male connector (wire A) and the other ends of wire B to the top side of the ESC.

Step 15: Mount the ESC on the frame using the 8mm screws. The ESC should be mounted on the opposite side of the frame from the motors.

Step 16: Solder the motor signal wires from step 4 to the FC. Make sure you connect the wires to the top side of the FC.

Step 17: Pass the motor signal wires through the frame and solder them to the corresponding motor posts on the ESC. Refer to the image below.

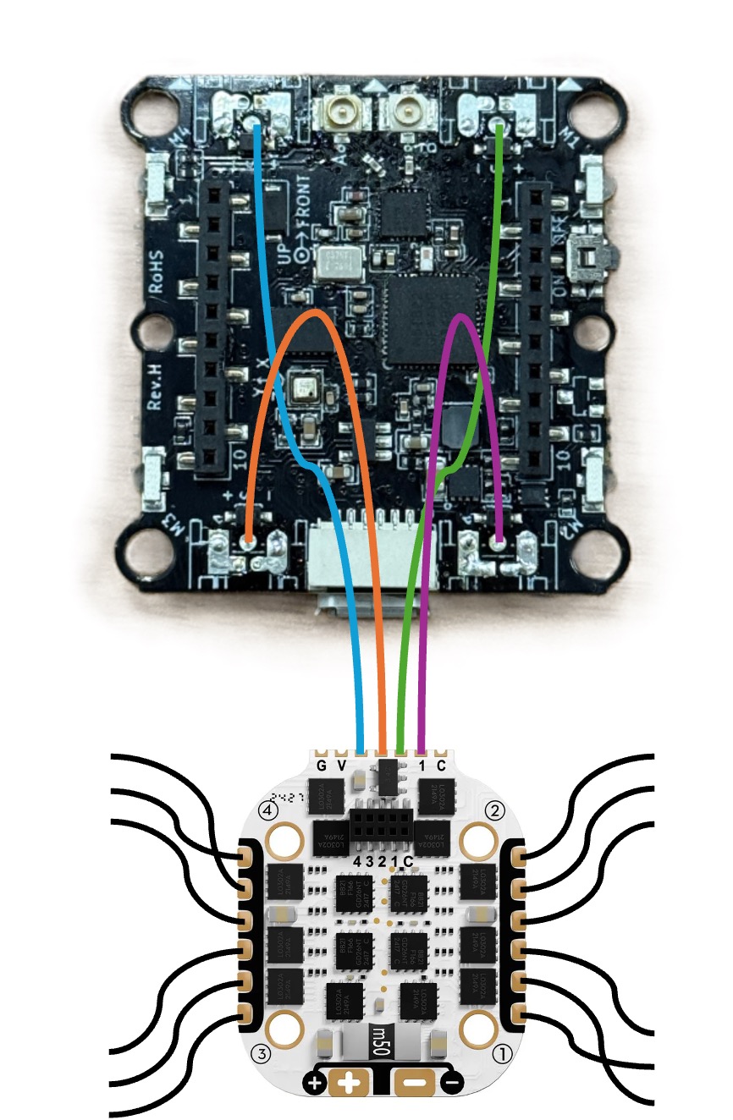
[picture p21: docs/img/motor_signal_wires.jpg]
Wring motors.


Step 18: Connect the FC anttena to the coaxical connector labeled as A on the top of the flight controller. Mount the flight controller on the frame using the 8mm screws and rubber balls.

Step 19: Solder motor wires from the motors to the ESC. Refer to the image above to see the correct wire ordering for each motor.

Finally your frame should look like this:

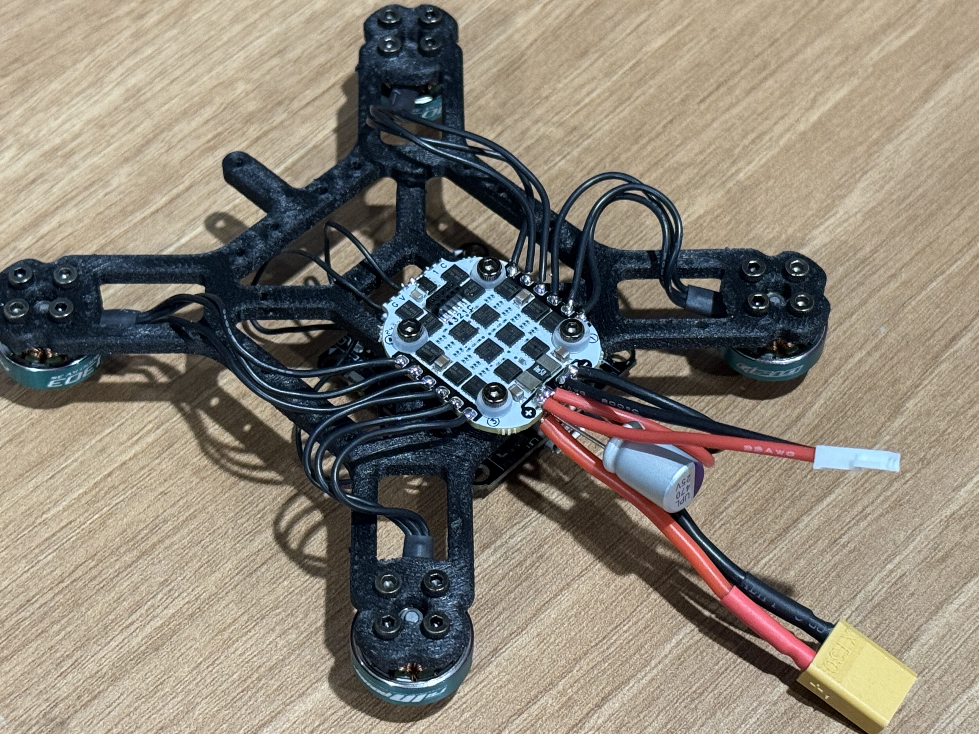
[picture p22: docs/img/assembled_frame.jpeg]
Assembled frame.


## RPi Baseboard and Power Assembly

Step 20: Solder the red wire of C to the VIN pin of the power Regualtor and red wire D to the OUT pin of the power Regualtor. Solder the black wires to the GND pins of the power Regualtor.

Step 21: Solder the power wires of the servo the the OUT and GND of the power regulator. Connect red to OUT and brown/black to GND.

Step 22: Solder the other ends of wire D to the RPi baseboard 5V and GND pins.

Step 23: Solder the yellow signal wires of the servos to the pins 12 and 35 on the RPi baseboard.

Step 24: Solder a 3-wire male connector to the RPi baseboard with wires for 5V, GND, and data. Connect the data wire to the pin 19 on the RPi baseboard.

Step 25: Solder 3 magnet wires to the input 5V, GND and Data pints of the 26-LED strip.

Step 26: Solder 2 magent wires to the 5V and GND pins of the 24-LED strip on its opposite side from the input pins.

Step 27: Connect the data pin of the 26-LED strip to the data pin of the 24-LED strip.

Step 28: Solder the 3-wire female connector to the other ends of the magnet wires. There should be 2 ground wires, 2 5V wires and one data wire. Use heat shring tubings to cover the connections.

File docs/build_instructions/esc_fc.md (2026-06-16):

# Configure ESC
1. After completing soldering connect the fc using a USB cable to your computer.
2. Open a browser and go to https://esc-configurator.com/.
3. Click on Select Serial Port and select "Crazyflie 2.x ...", Then click on Connect button in the top right corner.
4. After connecting, click of Read Settings button and then click on the blue button "Flash All ESCs" in the bottom of the page.
5. Select BLHeli_S and latest stable version and flash all ESCs.
6. After flashing is done, andjust the PPM min and max trhottle values using the sliders for each ESC to 1020 and 1980 as shown in the image below. Then, click on Write Settings button to save the settings.
7. Finaaly click on Disconnect button in the top right corner. 

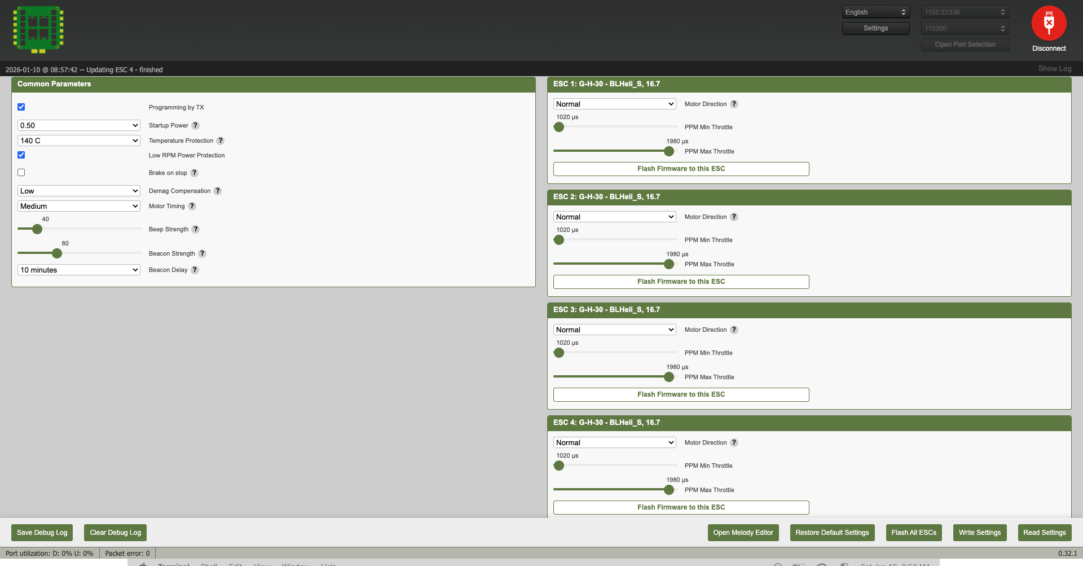
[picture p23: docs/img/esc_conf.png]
PPM min max settings


# Configure Crazyflie

## Configure ID
Install cflcient if not already installed.

```bash
pip3 install cflcient
```

Connect the CF Bolt using a USB cable to your computer and open cfclient by typing `cfclient` in your terminal.

Click on the Scan button on the top left and select "USB" from the dropdown menu. Then click on the Connect button in the top right corner.

Then go to the Connect Tab and select Configure 2.x.

Set the desired radio channel and id. We use channel 100.

Finally click on the Write button and disconnect the Crazyflie from the computer.

## Flash Firmware

Install the dependencies:
```bash
brew install gcc-arm-embedded coreutils gnu-sed
```

Clone the modified firmware from the following repository:

```bash
git clone --recursive https://github.com/flslab/crazyflie-firmware.git
cd crazyflie-firmware
```

Configure the firmware for CF Bolt:

```bash
make bolt_defconfig
```

Build the firmware:

```bash
make -j$(sysctl -n hw.ncpu)
```

Connect a battery to the FC and follwow these steps to manually entering bootloader mode:

- Turn the Crazyflie off
- Start the Crazyflie in bootloader mode by pressing the power button for 3 seconds. - Both the blue LEDs will blink.

Then, run the following command to flash the firmware to the FC:

```bash
make cload
```

For further information and instructions for Ubuntu and Windows, please refer to the original Bitcraze documentation here: https://github.com/bitcraze/crazyflie-firmware/blob/master/docs/building-and-flashing/build.md

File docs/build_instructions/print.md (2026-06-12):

# 3D Printing

Print the listed parts with the proper material based on the type of LightBender you are building.

## Semicircle LightBender Parts

| name | material | qty |
|---|---|-----|
| frame | PA6-CF | 1 |
| landing_gear | PA6-CF | 2 |
| semicircle | PA6-CF | 1 |
| shaft | PA6-CF | 1 |
| servo_case | PLA_CF | 1 |
| rpi_cover | PLA_CF | 1 |

## Linear LightBender Parts

| name | material | qty |
|---|---|-----|
| frame | PA6-CF | 1 |
| landing_gear | PA6-CF | 2 |
| rod_segment  | PA6-CF | 1 |
| tube_segment | PA6-CF | 1 |
| rod_joint | PA6-CF | 1 |
| tube_joint | PA6-CF | 1 |
| servo_case | PLA_CF | 1 |
| gearbox_case | PLA_CF | 1 |
| rpi_cover | PLA_CF | 1 |

## Notes

- We used Bambu X1 Carbon printer. 
- The 3d models are available in the `3d` directory under `linear` and `semicircle`.
- Dry the PA6-CF filament before printing for the best result.
- Use smooth PEI / high temp plate.
- Clean the oil, fingerprints, and printing waste from the plate before printing. Preferably wash it with water and soap.
- Apply 3D printing liquid glue to the plate when printing using PA6-CF.
- For printing the frame use `0.2mm strength` profile, and use `concentric` top and bottom
  surface pattern.
- For the rest of the parts use `0.16mm high quality` profile.
- After printing completes do not remove the parts. Wait util the plate temperature drops to around 50 to 40 degrees
  Celsius. Otherwise, the printed part may bend permanently.
- Store the filament in a sealed zip bag after use.

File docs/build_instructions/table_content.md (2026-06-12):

# Build Steps
1. Print 3D parts.
2. Solder and assemble components.
3. Setup FC and ESC.
4. Setup onboard computer.
5. Flight Test.

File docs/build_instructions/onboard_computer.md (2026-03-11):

# Setup Raspberry Pi CM5

## Install OS

## Install Offboard Controller

If cloning a private GitHub repository, you need to first authorize the RPi in the repository setting
1. Create an SSH key on the RPi:
```commandline
ssh-keygen -t ed25519 -C lbXX
```
The comment is optional and for better organization. XX is the ID of the LightBender, e.g., lb02.
Press enter for the rest of inputs.
2. In the GitHub repository, go to Settings > Deploy Keys.
3. Add deploy key and pase the content of `.ssh/id_ed25519.pub`.
```commandline
cat .ssh/id_ed25519.pub
```

Clone the repository using the SSH command, and then run the setup script.
```commandline
git clone git@github.com:flslab/fls-cf-offboard-controller.git
cd fls-cf-offboard-controller
bash setup.sh
```

This script automatically setups a Python environment, install dependencies, and configures the RPi.

Reboot after setup is completed.

## Test LED
Turns on 50 LEDs for 5 seconds.
```commandline
python led.py -t 5 -n 50
```

## Test Servo
```commandline
python servo_pwm.py -i -n 1
```
Then test different angles by inputting servo index and angle. For example 0 0 or 0 90.

## Test USB connection with CF Bolt
```commandline
python controller.py --ground-test
```

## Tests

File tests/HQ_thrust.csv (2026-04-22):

timestamp_iso | thrust_percent | thrust_cmd | n_loadcell | loadcell_mean | loadcell_median | loadcell_std | loadcell_min | loadcell_max | n_cf_samples | avg_motor_pwm | avg_battery_V | avg_pitch_deg
2026-02-11T15:39:00 | 1 | 10500 | 33 | 16.012424242424242 | 16.02 | 0.2641262754705396 | 15.42 | 16.64 | 39 | 10500 | 0 | 0.557477206
2026-02-11T15:39:09 | 10 | 15000 | 33 | 41.06727272727272 | 41.09 | 0.26970206626100324 | 40.44 | 41.57 | 39 | 15000 | 0 | -0.04555258
2026-02-11T15:39:17 | 20 | 20000 | 33 | 73.71000000000001 | 73.71 | 0.24595477226514748 | 73.17 | 74.15 | 40 | 20000 | 0 | -0.058364822
2026-02-11T15:39:26 | 30 | 25000 | 33 | 108.96575757575758 | 108.91 | 0.4673664936577484 | 107.92 | 110.13 | 40 | 25000 | 0 | -0.226860537
2026-02-11T15:39:35 | 40 | 30000 | 33 | 147.75393939393936 | 147.69 | 0.4517185198905629 | 146.77 | 148.58 | 40 | 30000 | 0 | -0.025240545
2026-02-11T15:39:43 | 50 | 35000 | 33 | 178.64121212121208 | 178.81 | 0.757849579 | 176.9 | 179.83 | 40 | 35000 | 0 | 0.19283162225037814
2026-02-11T15:39:52 | 60 | 40000 | 33 | 226.5178787878788 | 226.43 | 0.7402860831114475 | 225.35 | 228.21 | 39 | 40000 | 0 | 0.32217107522181976
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

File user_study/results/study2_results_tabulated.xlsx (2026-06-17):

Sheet: All Shapes and Conditions
Participant | Shape | Repetition | Duration | 0 mm | 3 mm | 10.1 mm | 30 mm | 100 mm
1 | Arrow | 1 | 17.132 | 10 | 8 | 9 | 6 | 2
1 | Arrow | 2 | 20.761 | 10 | 8 | 10 | 6 | 1
1 | Arrow | 3 | 20.328 | 10 | 10 | 8 | 4 | 0
1 | Blue Emoji | 1 | 26.926 | 10 | 9 | 8 | 6 | 3
1 | Emoji | 1 | 21.765 | 8 | 10 | 7 | 3 | 0
1 | Emoji | 2 | 14.767 | 6 | 8 | 10 | 4 | 0
1 | Emoji | 3 | 12.832 | 10 | 10 | 8 | 6 | 0
1 | Letter S | 1 | 23.266 | 9 | 10 | 6 | 3 | 0
1 | Letter S | 2 | 30.999 | 10 | 10 | 8 | 6 | 0
1 | Letter S | 3 | 57.997 | 10 | 6 | 8 | 4 | 0
1 | Letter X | 1 | 155.53 | 9 | 10 | 9 | 4 | 0
2 | Arrow | 1 | 37.529 | 10 | 9 | 7 | 4 | 1
2 | Arrow | 2 | 32.162 | 6 | 10 | 9 | 3 | 1
2 | Arrow | 3 | 26.532 | 10 | 6 | 7 | 3 | 0
2 | Blue Emoji | 1 | 70.46 | 10 | 9 | 6 | 3 | 0
2 | Emoji | 1 | 33.966 | 10 | 8 | 7 | 3 | 1
2 | Emoji | 2 | 52.132 | 9 | 9 | 10 | 3 | 1
2 | Emoji | 3 | 36.132 | 10 | 10 | 8 | 4 | 1
2 | Letter S | 1 | 42.165 | 10 | 10 | 7 | 3 | 0
2 | Letter S | 2 | 29.963 | 10 | 9 | 5 | 3 | 0
2 | Letter S | 3 | 28.467 | 10 | 10 | 5 | 3 | 0
2 | Letter X | 1 | 171.813 | 10 | 10 | 8 | 5 | 0
3 | Arrow | 1 | 17.666 | 9 | 8 | 10 | 3 | 1
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

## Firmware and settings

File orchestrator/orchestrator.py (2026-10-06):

import argparse
import io
import os
import yaml
import json
import time
import zmq
import threading
import http.server
import socketserver
import sys
import signal
import shutil
import socket
import logging
import shlex
from datetime import datetime
from functools import partial
from fabric import Connection
from invoke.exceptions import CommandTimedOut
import concurrent.futures

# Assumed local modules based on your import list
from logger import setup_logging
from restart import reboot_crazyflie
from switch_network import apply_network_mode
from marker_grid_client import MarkerGridClient

# from Interaction.vicon_noise_tracker import run_tracker
from pathlib import Path

BASE_DIR = Path(__file__).resolve().parent

MANIFEST_FILE = BASE_DIR / 'swarm_manifest.yaml'
DRONE_SCRIPT = 'controller.py'
CAMERA_SCRIPT = 'camera_node.py'


def validate_marker_tile_ownership(manifest):
    """Validate optional per-drone landing tiles and reject shared ownership."""
    owners = {}
    for drone in manifest.get('drones', []):
        tile = drone.get('marker_tile')
        if tile is None:
            continue
        if (not isinstance(tile, (list, tuple)) or len(tile) != 2 or
                not all(isinstance(value, int) and not isinstance(value, bool)
                        for value in tile)):
            raise ValueError(
                f"Drone {drone.get('id')} has invalid marker_tile {tile}"
            )
        key = tuple(tile)
        if key in owners:
            raise ValueError(
                f"Marker tile {key} is assigned to both {owners[key]} and "
                f"{drone.get('id')}"
            )
        owners[key] = drone.get('id')

    config = manifest.get('marker_grid_node')
    if not owners and config is None:
        return
    if not isinstance(config, dict):
        raise ValueError(
            "marker_grid_node configuration is required for marker_tile drones"
        )
    port = config.get('port')
    if not isinstance(port, int) or isinstance(port, bool) or not 1 <= port <= 65535:
        raise ValueError("marker_grid_node.port must be in [1, 65535]")
    for field in ('ip', 'user', 'work_dir', 'grid_file'):
        value = config.get(field)
        if not isinstance(value, str) or not value.strip():
            raise ValueError(f"marker_grid_node.{field} must be a non-empty string")
    if config.get('initial_mode', 'blink') not in ('off', 'static', 'blink'):
        raise ValueError("marker_grid_node.initial_mode must be off, static, or blink")
    for field, default in (('gpio', 10), ('dma_channel', 10)):
        value = config.get(field, default)
        if not isinstance(value, int) or isinstance(value, bool) or value < 0:
            raise ValueError(f"marker_grid_node.{field} must be a non-negative integer")
    frequency_hz = config.get('frequency_hz', 800000)
    if (not isinstance(frequency_hz, int) or isinstance(frequency_hz, bool) or
            frequency_hz <= 0):
        raise ValueError("marker_grid_node.frequency_hz must be a positive integer")
    for field in ('mygrid_level', 'hypergrid_level'):
        value = config.get(field, 255)
        if not isinstance(value, int) or isinstance(value, bool) or not 0 <= value <= 255:
            raise ValueError(f"marker_grid_node.{field} must be in [0, 255]")
    if 'hypergrid_tiles' in config:
        hypergrid_tiles = config['hypergrid_tiles']
        if not isinstance(hypergrid_tiles, list):
            raise ValueError("marker_grid_node.hypergrid_tiles must be a list")
        seen = set()
        for tile in hypergrid_tiles:
            if (not isinstance(tile, (list, tuple)) or len(tile) != 2 or
                    not all(isinstance(value, int) and not isinstance(value, bool)
                            for value in tile)):
                raise ValueError(
                    "marker_grid_node.hypergrid_tiles entries must be [i, j] "
                    "integer pairs"
                )
            key = tuple(tile)
            if key in seen:
                raise ValueError(
                    f"marker_grid_node.hypergrid_tiles contains duplicate {key}"
                )
            seen.add(key)


class SwarmOrchestrator:
    def __init__(self, args):
        setup_logging()
        self.logger = logging.getLogger(__name__)
        self.args = args

        # Configuration State
        self.manifest = self._load_manifest()
        self.ctrl_cfg = self.manifest['controller']
        if args.http_port:
            self.ctrl_cfg['http_port'] = args.http_port
        if args.zmq_cmd_port:
            self.ctrl_cfg['zmq_cmd_port'] = args.zmq_cmd_port
        if args.zmq_ack_port:
            self.ctrl_cfg['zmq_ack_port'] = args.zmq_ack_port
        self.drones = self.manifest.get('drones', [])
        validate_marker_tile_ownership(self.manifest)
        self.camera_cfg = self.manifest.get('camera_node')
        self.radio_node = self.manifest.get('radio_node')
        self.marker_grid_cfg = self.manifest.get('marker_grid_node')
        self.common_cfg = self.manifest['common']
        self.missions = self._load_missions()
        self.mission = self.missions[0] if self.missions else None

        # Runtime State
        self.tag = None
        self.running = threading.Event()
        self.took_off = False
        self.emergency = False
        self.pending_downloads = self._load_previous_downloads()
        self.landed_drones = set()
        self.ready_ids = set()

        self.loadcell_thread = None
        self.vicon_tracker_thread = None

        # Network Resources
        self.zmq_context = None
        self.pub_socket = None
        self.pull_socket = None
        self.http_server = None
        self.marker_grid_client = None

        # Bind signal handlers for graceful exit
        # signal.signal(signal.SIGINT, self._signal_handler)
        # signal.signal(signal.SIGTERM, self._signal_handler)

        # Blender monitor socket (pushes status to Blender addon)
        self._blender_monitor_host = '127.0.0.1'
        self._blender_monitor_port = 5598
        if args.blender:
            parts = args.blender.split(':')
            if len(parts) == 2:
                self._blender_monitor_host = parts[0]
                self._blender_monitor_port = int(parts[1])
            else:
                self.logger.warning(f"Invalid --blender format '{args.blender}', expected host:port. Using defaults.")
        self._blender_monitor_sock = None
        self._blender_monitor_lock = threading.Lock()
        self._confirm_launch_event = threading.Event()

    def _load_manifest(self):
        with open(MANIFEST_FILE) as f:
            return yaml.safe_load(f)

    def _load_missions(self):
        missions = []
        files = self.ctrl_cfg.get('mission_files', [])
        if not files and 'mission_file' in self.ctrl_cfg:
            files = [self.ctrl_cfg['mission_file']]
        
        self.mission_filepaths = []
        for file in files:
            path = os.path.join(self.ctrl_cfg['mission_path'], file)
            self.mission_filepaths.append(path)
            with open(path) as f:
                missions.append(yaml.safe_load(f))
        return missions

    def _load_previous_downloads(self):
        try:
            with open(self.ctrl_cfg['downloads_file']) as f:
                return json.load(f)
        except (FileNotFoundError, json.JSONDecodeError):
            return []

    def _signal_handler(self, sig, frame):
        self.logger.warning(f"Signal {sig} received. Initiating Emergency Shutdown...")
        self.emergency_stop()

    def setup_network(self):
        """Initializes ZMQ sockets and HTTP server."""
        # HTTP Server
        port = self.ctrl_cfg['http_port']
        directory = self.ctrl_cfg['mission_path']

        # Reuse address to prevent 'Address already in use' on quick restarts
        socketserver.TCPServer.allow_reuse_address = True

        handler = partial(http.server.SimpleHTTPRequestHandler, directory=directory)
        self.http_server = socketserver.TCPServer(("", port), handler)

        http_thread = threading.Thread(target=self.http_server.serve_forever, daemon=True)
        http_thread.start()
        self.logger.info(f"HTTP Config Server running on port {port} serving {directory}")

        # ZMQ
        self.zmq_context = zmq.Context()
        self.pub_socket = self.zmq_context.socket(zmq.PUB)
        self.pub_socket.bind(f"tcp://*:{self.ctrl_cfg['zmq_cmd_port']}")

        self.pull_socket = self.zmq_context.socket(zmq.PULL)
        self.pull_socket.bind(f"tcp://*:{self.ctrl_cfg['zmq_ack_port']}")

        # Set a timeout on receive so we can check for shutdown flags periodically
        self.pull_socket.setsockopt(zmq.RCVTIMEO, 1000)

        self.logger.info(f"ZMQ Server Online at {self.ctrl_cfg['ip']}")

    def _get_drone_cmd(self, drone):
        if self.args.interaction:
            return self._get_drone_cmd_interaction(drone)
        elif self.args.illumination:
            return self._get_drone_cmd_illumination(drone)
        elif self.args.morphing:
            return self._get_drone_cmd_morphing(drone)
        else:
            raise Exception("mode not supported")

    def _get_drone_cmd_interaction(self, drone):
        alt = self.mission['drones'][drone['id']]['target'][2]
        servo_count = drone.get('servo_count', 2)
        led_count = drone.get('led_count', 50)
        radio_arg = f"--radio {drone['uri']}" if self.args.radio else ""
        droneless_arg = "--droneless" if self.args.droneless else ""
        p = drone.get('init_pos', None)
        obj_name = drone.get('label', None)
        if p:
            mocap_args = f"--init-pos {p[0]} {p[1]} {p[2]} --vicon-mode pointcloud "
        elif obj_name:
            mocap_args = f"--obj-name {obj_name} --vicon-mode rigidbody "

        extra_markers = self.manifest.get('apparatus', None)
        extra_marker_args = ""
        if extra_markers:
            for m in extra_markers:
                extra_marker_args += f"--extra-marker {m['id']} "
                init_pos = m.get("init_pos")
                if init_pos is not None:
                    extra_marker_args += f"{' '.join(str(c) for c in m['init_pos'])} "
        cmd = [
            f"cd {self.common_cfg['work_dir']} && "
            f"source {self.common_cfg['venv_path']}/bin/activate && "
            "git pull && "
            f"nohup python3 {DRONE_SCRIPT} "
            f"--orchestrated --interaction --tag {self.tag} ",
            f"--intractable-illumination" if getattr(self.args, 'intractable_illumination', False) else "",
            f"--ground-test " if self.args.ground else "",
            f"{radio_arg} "
            f"{extra_marker_args} "
            f"--vicon {mocap_args} "
            f"--drone-id {drone['id']} ",
            f"--led --led-count {led_count} " if led_count > 0 and not self.args.radio else " ",
            f"--servo --servo-type {drone.get('type', 'H')} --servo-count {servo_count} " if servo_count > 0 and not self.args.radio else " ",
            f"--takeoff-altitude {alt} "
            "--smooth-controller-rate 100 "
            "--log "
            f"{droneless_arg} "
            "--cf-log-period 10 "
            # "--skip-takeoff --skip-landing "
            f"> drone_{drone['id']}.log 2>&1 < /dev/null &",
        ]

        # If a reference object is configured, also launch the noise tracker on the drone.
        ref_obj = self.common_cfg.get('reference_object')
        if ref_obj:
            vicon_log = f"{self.common_cfg['work_dir']}/logs/vicon_{self.tag}.json"
            cmd.append(
                f"cd {self.common_cfg['work_dir']} && "
                f"source {self.common_cfg['venv_path']}/bin/activate && "
                f"nohup python3 Interaction/vicon_noise_tracker.py "
                f"--subject {ref_obj} --duration 10 "
                f"--out {vicon_log} "
                f"> vicon_noise.log 2>&1 < /dev/null &"
            )

        return f" ".join(cmd)

    def _get_drone_cmd_illumination(self, drone):
        self.logger.debug(drone)
        drone_mission = self.mission['drones'][drone['id']]
        alt = drone_mission['target'][2]
        servo_count = drone.get('servo_count', 2)
        servo_offsets = drone.get('servo_offsets', [0.0] * servo_count)
        led_count = drone.get('led_count', 50)
        init_yaw = drone.get('init_yaw', 0)
        ground_test = drone.get('ground_test', False)
        marker_id = drone.get('marker_id', -1)
        target_id = 0
        if drone_mission.get('relative_anchor'):
            anchor_id = drone_mission['relative_anchor']['id']
            anchor_drone = self._get_drone_by_id(anchor_id)
            if anchor_drone:
                target_id = anchor_drone.get('marker_id', 0)
            else:
                target_id = drone_mission['relative_anchor'].get('marker_id', 0)
        if drone.get('obj_name'):
            mocap_args = f"--obj-name {drone['obj_name']} --vicon-mode rigidbody --vicon-full-pose "
        else:
            p = drone['init_pos']
            mocap_args = f"--init-pos {p[0]} {p[1]} {p[2]} --vicon-mode pointcloud --init-yaw {init_yaw} "
            
        viewpoint_arg = f"--viewpoint {drone['viewpoint'][0]} {drone['viewpoint'][1]} {drone['viewpoint'][2]} " if 'viewpoint' in drone else ""
        reference_arg = f"--reference {drone['reference'][0]} {drone['reference'][1]} {drone['reference'][2]} " if 'reference' in drone else ""
        anchor_arg = f"--anchor {drone['anchor'][0]} {drone['anchor'][1]} {drone['anchor'][2]} " if 'anchor' in drone else ""
        tracker_arg = self._get_marker_grid_tracker_arg(drone)

        smooth_controller_rate = f"--smooth-controller-rate 100"
        localization_flags = ""
        if drone.get('flowdeck'):
            localization_flags = "--check-deck bcFlow2" 
        elif drone.get('vicon'):
            localization_flags = "--vicon"
        if drone.get('save_vicon'):
            localization_flags += " --save-vicon "
        
        cmd = [
            f"cd {self.common_cfg['work_dir']} && ",
            f"source {self.common_cfg['venv_path']}/bin/activate && ",
            "git pull && ",
            f"nohup python3 {DRONE_SCRIPT} ",
            f"--illumination --orchestrated --tag {self.tag} ",
            "--ground-test " if self.args.ground else f" {localization_flags} {mocap_args} ",
            f"--marker-id {marker_id} " if marker_id is not None else "",
            f"--target-id {target_id} " if target_id is not None else "",
            f"{viewpoint_arg}",
            f"{anchor_arg}",
            f"{reference_arg}",
            f"--drone-id {drone['id']} ",
            f"{tracker_arg}",
            f"--led --led-brightness 0.95 --led-count {led_count} " if led_count > 0 else " ",
            f"--servo --servo-type {drone['type']} --servo-count {servo_count} " if servo_count > 0 else " ",
            f"--servo-offsets {' '.join(str(o) for o in servo_offsets)} " if servo_count > 0 else " ",
            f"--takeoff-altitude {alt} ",
            f"{smooth_controller_rate}",
            "--camera-offset 0.04 0 0 --marker-offset 0 0 0",
            "--velocity-p 1.0",
            "--log",
            # "--skip-arm",
            f"--ground-test" if ground_test else "",
            f"> drone_{drone['id']}.log 2>&1 < /dev/null &",
        ]

        return " ".join(cmd)

    def _get_marker_grid_tracker_arg(self, drone):
        """Launch grid PnP whenever this drone owns a short-range tile."""
        if drone.get('marker_tile') is None:
            return ""
        return "--tracker"

    def _get_marker_grid_cmd(self):
        """Build the detached command run on the dedicated marker-grid Pi."""
        config = self.marker_grid_cfg
        work_dir = shlex.quote(config['work_dir'])
        python = shlex.quote(
            f"{config.get('venv_path', config['work_dir'] + '/.venv')}/bin/python3"
        )
        grid_file = shlex.quote(config['grid_file'])
        options = [
            "--host 0.0.0.0",
            f"--port {config['port']}",
            f"--gpio {config.get('gpio', 10)}",
            f"--mygrid-level {config.get('mygrid_level', 255)}",
            f"--hypergrid-level {config.get('hypergrid_level', 255)}",
            f"--initial-mode {shlex.quote(config.get('initial_mode', 'blink'))}",
        ]
        if 'hypergrid_tiles' in config:
            tiles = shlex.quote(
                json.dumps(config['hypergrid_tiles'], separators=(',', ':'))
            )
            options.append(f"--hypergrid-tiles {tiles}")
        invocation = f"{python} -m marker_grid_controller {grid_file} {' '.join(options)}"
        return (
            f"cd {work_dir} && git pull && "
            # f"{invocation} --check && "
            f"nohup {invocation} > marker_grid.log 2>&1 < /dev/null &"
        )

    def _boot_marker_grid(self):
        if not self.marker_grid_cfg:
            return
        if not self._boot_remote_node(
            self.marker_grid_cfg, self._get_marker_grid_cmd(), "Marker grid"
        ):
            raise RuntimeError("failed to launch marker-grid node")
        self.marker_grid_client = MarkerGridClient(
            self.marker_grid_cfg['ip'], self.marker_grid_cfg['port']
        )
        self.marker_grid_client.wait_until_ready(
            self.marker_grid_cfg.get('startup_timeout_s', 15.0)
        )
        self.logger.info("Marker-grid node ready")

    def _set_marker_grid_mode(self, mode, drone_id=None):
        if not self.marker_grid_client:
            return
        tile = None
        if drone_id is not None:
            drone = self._get_drone_by_id(drone_id)
            if drone is None or drone.get('marker_tile') is None:
                raise ValueError(f"Drone {drone_id} does not own a marker tile")
            tile = drone['marker_tile']
        response = self.marker_grid_client.set_mode(mode, tile)
        target = "all tiles" if tile is None else f"tile {tuple(tile)}"
        self.logger.info(
            f"Marker grid {target} -> {mode} ({response['changed']} changed)"
        )

    @staticmethod
    def _snake_order_marker_tiles(tiles):
        """Order (i, j) = (x, y) tiles along fixed-x serpentine rows."""
        rows = {}
        for tile in tiles:
            if (not isinstance(tile, (list, tuple)) or len(tile) != 2 or
                    not all(isinstance(value, int) and not isinstance(value, bool)
                            for value in tile)):
                raise ValueError(f"Invalid MyGrid tile coordinate: {tile}")
            i, j = tile
            rows.setdefault(i, set()).add(j)

        ordered = []
        for row_number, i in enumerate(sorted(rows)):
            columns = sorted(rows[i], reverse=bool(row_number % 2))
            ordered.extend((i, j) for j in columns)
        return ordered

    def _get_marker_grid_tiles(self):
        """Read all MyGrid coordinates advertised by the grid controller."""
        status = self.marker_grid_client.status()
        tiles = status.get('tiles')
        if isinstance(tiles, dict):
            tiles = list(tiles)
        if not isinstance(tiles, list):
            raise RuntimeError(
                "marker-grid status did not include a tiles list"
            )
        if not tiles:
            raise RuntimeError("marker-grid status reported no MyGrid tiles")

        coordinates = []
        for tile in tiles:
            if isinstance(tile, dict):
                tile = tile.get('tile')
            elif isinstance(tile, str):
                try:
                    tile = [int(value.strip()) for value in tile.split(',')]
                except ValueError:
                    pass
            coordinates.append(tile)
        return self._snake_order_marker_tiles(coordinates)

    def run_marker_grid_test(self):
        """Interactively exercise every MyGrid while keeping HyperGrid on."""
        if not self.marker_grid_cfg:
            raise RuntimeError(
                "--test-marker-grid requires marker_grid_node in the manifest"
            )

        self._boot_marker_grid()
        try:
            # A whole-grid static command enables HyperGrid and every MyGrid.
            self._set_marker_grid_mode("static")
            tiles = self._get_marker_grid_tiles()
            self.logger.info(
                f"Marker-grid test ready: HyperGrid and {len(tiles)} "
                "MyGrids are ON"
            )
            for index, tile in enumerate(tiles, start=1):
                input(
                    f">>> MyGrid {index}/{len(tiles)} {tile}: "
                    "press ENTER to turn OFF..."
                )
                self.marker_grid_client.set_mode("off", tile)
                input(
                    f">>> MyGrid {index}/{len(tiles)} {tile}: "
                    "press ENTER to turn ON..."
                )
                self.marker_grid_client.set_mode("static", tile)
            self.logger.info("Marker-grid test complete")
        finally:
            self._stop_marker_grid_controller()
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

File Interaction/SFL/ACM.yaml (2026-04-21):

name: Scene
drones:
  lb2:
    target: [0.1987, -0.1823, 1.065, 0.0, 0.0]
    waypoints: [[0.1987, -0.1823, 1.065, 0.0, 0.0], [0.1987, -0.1823, 1.065, 0.0, 14.9583]]
    delta_t: 0.0
    iterations: 1
    params:
      linear: true
      relative: false
    servos: [[110.0, 430.0], [110.0, 430.0]]
    pointers: [[3.12, 47.79], [3.12, 47.79]]
    led:
      mode: "expression"
      rate: 50
      formula: "([0, 0, 0]) if i < p0 else ([255, 255, 255]) if i < p1 else ([0, 0, 0])"
  lb8:
    target: [0.0, 0.235, 1.08, 0.0, 0.0]
    waypoints: [[0.0, 0.235, 1.08, 0.0, 0.0], [0.0, 0.235, 1.08, 0.0, 14.9583]]
    delta_t: 0.0
    iterations: 1
    params:
      linear: true
      relative: false
    servos: [[110.0, 430.0], [110.0, 430.0]]
    pointers: [[1.0, 50.0], [1.0, 50.0]]
    led:
      mode: "expression"
      rate: 50
      formula: "([0, 0, 0]) if i < p0 else ([255, 255, 255]) if i < p1 else ([0, 0, 0])"
  lb3:
    target: [0.229, 0.1168, 1.0627, 0.0, 0.0]
    waypoints: [[0.229, 0.1168, 1.0627, 0.0, 0.0], [0.229, 0.1168, 1.0627, 0.0, 14.9583]]
    delta_t: 0.0
    iterations: 1
    params:
      linear: true
      relative: false
    servos: [[110.0, 430.0], [110.0, 430.0]]
    pointers: [[3.44, 47.46], [3.44, 47.46]]
    led:
      mode: "expression"
      rate: 50
      formula: "([0, 0, 0]) if i < p0 else ([255, 255, 255]) if i < p1 else ([0, 0, 0])"
  lb4:
    target: [-0.3991, -0.1319, 1.0277, 0.0, 0.0]
    waypoints: [[-0.3991, -0.1319, 1.0277, 0.0, 0.0], [-0.3991, -0.1319, 1.0277, 0.0, 14.9583]]
    delta_t: 0.0
    iterations: 1
    params:
      linear: true
      relative: false
    servos: [[60.0, 300.0], [60.0, 300.0]]
    pointers: [[9.69, 41.48], [9.69, 41.48]]
    led:
      mode: "expression"
      rate: 50
      formula: "([0, 0, 0]) if i < p0 else ([255, 255, 255]) if i < p1 else ([0, 0, 0])"
  lb7:
    target: [0.0, 0.01, 0.94, 0.0, 0.0]
    waypoints: [[0.0, 0.01, 0.94, 0.0, 0.0], [0.0, 0.01, 0.94, 0.0, 14.9583]]
    delta_t: 0.0
    iterations: 1
    params:
      linear: true
      relative: false
    servos: [[180.0, 300.0], [180.0, 300.0]]
    pointers: [[12.0, 33.03], [12.0, 33.03]]
    led:
      mode: "expression"
      rate: 50
      formula: "([0, 0, 0]) if i < p0 else ([255, 255, 255]) if i < p1 else ([0, 0, 0])"
  lb1:
    target: [0.0, -0.315, 0.99, 0.0, 0.0]
    waypoints: [[0.0, -0.315, 0.99, 0.0, 0.0], [0.0, -0.315, 0.99, 0.0, 14.9583]]
    delta_t: 0.0
    iterations: 1
    params:
      linear: true
      relative: false
    servos: [[180.0, 360.0], [180.0, 360.0]]
    pointers: [[39.0, 50.0], [39.0, 50.0]]
    led:
      mode: "expression"
      rate: 50
      formula: "([0, 0, 0]) if i < p0 else ([255, 255, 255]) if i < p1 else ([0, 0, 0])"
  lb5:
    target: [-0.1994, 0.0109, 1.0951, 0.0, 0.0]
    waypoints: [[-0.1994, 0.0109, 1.0951, 0.0, 0.0], [-0.1994, 0.0109, 1.0951, 0.0, 14.9583]]
    delta_t: 0.0
    iterations: 1
    params:
      linear: true
      relative: false
    servos: [[60.0, 180.0], [60.0, 180.0]]
    pointers: [[18.47, 39.15], [18.47, 39.15]]
    led:
      mode: "expression"
      rate: 50
      formula: "([0, 0, 0]) if i < p0 else ([255, 255, 255]) if i < p1 else ([0, 0, 0])"

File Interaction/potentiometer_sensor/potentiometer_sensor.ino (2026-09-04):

// Potentiometer distance measurement with low-pass filtering and
// multi-point piecewise-linear calibration.
//
// Typical wiring:
//   Red    -> Arduino 5V (or 3.3V on a 3.3V board)
//   Green  -> Arduino GND
//   Yellow -> Arduino A0
//
// Wire colors are not guaranteed. The signal wire must be the wiper of the
// potentiometer. Swapping Red and Green only reverses the measurement direction.

const uint8_t POT_PIN = A0;

// ADC settings.
const int ADC_MAX_VALUE = 1023;

// Measured calibration points. Raw ADC values decrease as distance increases.
// ADC 1023 corresponds to 0 mm (fully released/reference position).
const uint8_t CALIBRATION_COUNT = 11;

const float RAW_CALIBRATION[CALIBRATION_COUNT] = {
  1023.0f, 987.0f, 974.0f, 965.0f, 953.0f, 946.0f,
  935.0f, 925.0f, 876.0f, 665.0f, 500.0f
};

const float DISTANCE_MM[CALIBRATION_COUNT] = {
  0.0f, 1.3f, 2.2f, 3.3f, 4.8f, 5.6f,
  6.6f, 7.1f, 8.7f, 9.7f, 10.4f
};

// Exponential low-pass filter. Larger values respond faster but filter less.
// A practical range is approximately 0.05 to 0.30.
const float FILTER_ALPHA = 0.50f;

// Sampling/output interval. 20 ms = 50 samples per second.
const unsigned long SAMPLE_INTERVAL_MS = 20;

float filteredPotValue = 0.0f;
unsigned long lastSampleTime = 0;

// Estimate the Nano supply using the AVR's internal nominal 1.1 V reference.
// Absolute accuracy depends on the chip's bandgap tolerance, but fast changes
// reliably reveal supply droop or a brownout precursor during motor startup.
unsigned long readSupplyMillivolts() {
#if defined(__AVR_ATmega328P__) || defined(__AVR_ATmega168__)
  ADMUX = _BV(REFS0) | _BV(MUX3) | _BV(MUX2) | _BV(MUX1);
  delayMicroseconds(250);
  ADCSRA |= _BV(ADSC);
  while (bit_is_set(ADCSRA, ADSC)) {
  }
  const uint8_t low = ADCL;
  const uint8_t high = ADCH;
  const unsigned int result = (high << 8) | low;
  if (result == 0) {
    return 0;
  }
  return 1125300UL / result;
#else
  // This sketch is calibrated for a classic 5 V Nano. Unsupported boards
  // retain a useful nominal field rather than failing compilation.
  return 5000UL;
#endif
}

float computePosition(float rawValue) {
  // Clamp readings outside the calibrated range. ADC 1023 is the 0 mm
  // reference and is also the upper limit of the Uno's 10-bit ADC.
  if (rawValue >= RAW_CALIBRATION[0]) {
    return DISTANCE_MM[0];
  }
  if (rawValue <= RAW_CALIBRATION[CALIBRATION_COUNT - 1]) {
    return DISTANCE_MM[CALIBRATION_COUNT - 1];
  }

  // Find the two measured points surrounding the current reading, then
  // interpolate only within that interval. This follows the measured
  // nonlinearity without the endpoint oscillation of a high-order polynomial.
  for (uint8_t i = 0; i < CALIBRATION_COUNT - 1; ++i) {
    const float rawHigh = RAW_CALIBRATION[i];
    const float rawLow = RAW_CALIBRATION[i + 1];

    if (rawValue <= rawHigh && rawValue >= rawLow) {
      const float fraction = (rawHigh - rawValue) / (rawHigh - rawLow);
      return DISTANCE_MM[i]
           + fraction * (DISTANCE_MM[i + 1] - DISTANCE_MM[i]);
    }
  }

  // This should be unreachable because values outside the table are clamped.
  return DISTANCE_MM[CALIBRATION_COUNT - 1];
}

void setup() {
  Serial.begin(115200);

  // Initialize the filter with a real measurement. This avoids a false ramp
  // from zero during the first few readings.
  const int firstReading = analogRead(POT_PIN);
  filteredPotValue = firstReading;
  lastSampleTime = millis();

  Serial.println(
    "time_ms,raw,filtered,voltage,distance_mm,supply_voltage"
  );
}

void loop() {
  const unsigned long now = millis();

  // Unsigned subtraction remains valid when millis() wraps around.
  if (now - lastSampleTime < SAMPLE_INTERVAL_MS) {
    return;
  }
  lastSampleTime = now;

  const float supplyVoltage = readSupplyMillivolts() / 1000.0f;

  // The supply measurement selects the internal bandgap channel. Discard the
  // first A0 conversion after switching back so it cannot bias the sensor.
  analogRead(POT_PIN);
  const int rawPotValue = analogRead(POT_PIN);

  filteredPotValue = FILTER_ALPHA * rawPotValue
                   + (1.0f - FILTER_ALPHA) * filteredPotValue;

  const float voltage = filteredPotValue
                      * supplyVoltage / ADC_MAX_VALUE;
  const float distanceMm = computePosition(filteredPotValue);

  // CSV output for Serial Monitor or Serial Plotter.
  Serial.print(now);
  Serial.print(',');
  Serial.print(rawPotValue);
  Serial.print(',');
  Serial.print(filteredPotValue, 2);
  Serial.print(',');
  Serial.print(voltage, 3);
  Serial.print(',');
  Serial.print(distanceMm, 3);
  Serial.print(',');
  Serial.println(supplyVoltage, 3);
}

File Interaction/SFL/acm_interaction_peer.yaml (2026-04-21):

name: acm_interaction_peer
drones:
  lb2:
    target: [0.2987, -0.1823, 1.065, 0.0, 0.0]
    waypoints: []
    delta_t: 60
    iterations: 1
    interaction: peer
    params:
      linear: true
      relative: false
    servos: [[110.0, 430.0]]
    color: [227, 253, 255]
  lb8:
    target: [0.0, 0.235, 1.08, 0.0, 0.0]
    waypoints: []
    delta_t: 60
    iterations: 1
    interaction: peer
    params:
      linear: true
      relative: false
    servos: [[110.0, 430.0]]
    color: [227, 253, 255]
  lb3:
    target: [0.329, 0.1168, 1.0627, 0.0, 0.0]
    waypoints: []
    delta_t: 60
    iterations: 1
    interaction: peer
    params:
      linear: true
      relative: false
    servos: [[110.0, 430.0]]
    color: [227, 253, 255]
  lb4:
    target: [-0.5991, -0.1319, 1.0277, 0.0, 0.0]
    waypoints: []
    delta_t: 60
    iterations: 1
    interaction: peer
    params:
      linear: true
      relative: false
    servos: [[60.0, 300.0]]
    color: [227, 253, 255]
  lb7:
    target: [0.0, 0.01, 0.94, 0.0, 0.0]
    waypoints: []
    delta_t: 60
    iterations: 1
    interaction: peer
    params:
      linear: true
      relative: false
    servos: [[180.0, 300.0]]
    color: [227, 253, 255]
  lb1:
    target: [0.0, -0.315, 0.99, 0.0, 0.0]
    waypoints: []
    delta_t: 60
    iterations: 1
    interaction: peer
    params:
      linear: true
      relative: false
    servos: [[180.0, 360.0]]
    color: [227, 253, 255]
  lb5:
    target: [-0.2994, 0.0109, 1.0951, 0.0, 0.0]
    waypoints: []
    delta_t: 60
    iterations: 1
    interaction: peer
    params:
      linear: true
      relative: false
    servos: [[60.0, 180.0]]
    color: [227, 253, 255]

Interaction:
  action: translation
  peer_transport: tcp
  config:
    delta_v: 0.2
    pos_threshold: 0.02
    z: 1
    friction_coefficient: 0
    base_attitude: -1
    duration: 60
    v_scalar: [10, 10, 3]
    grace_time: 2

boundary_limits:
  x_min: -7.0
  x_max: 5.0
  y_min: -4.0
  y_max: 4.0
  z_min: 0.3
  z_max: 2

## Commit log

2026-02-16 add perspective camera model
2026-02-18 add yaw
2026-03-04 added visualizer for 2d and 3d sequence frames
2026-03-06 added camera field of view to morphingEmulator
2026-03-06 feat: fixed out of order frames in video render
2026-03-07 feat: added visualizer with camera perspective, lines to indicate the LEDs for FLS need to still be worked on
2026-03-27 add velocity, acceleration, jerk, and snap limits for ground truth trajectory generation
2026-03-29 relative rmse with kinematics
2026-03-31 dix move toward going past the camera
2026-04-01 feat: added LED formula and modified controller code to compute servo angles in real-time
2026-04-05 add illuminate button
2026-04-06 fix yaw assignment for coherent headings
2026-04-17 add camera to mission file
2026-04-20 support led masking
2026-04-23 update sample
2026-04-28 fix button states
2026-05-04 update submodule to track master branch
2026-05-05 add support for flowdeck
2026-05-13 add init yaw
2026-05-26 add ground test to manifest
2026-06-09 add 3d parts
    [gearbox_case.3mf, rod_joint.3mf, rod_segment.3mf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]
2026-06-12 update docs
    [frame.3mf, gearbox_case.3mf, landing_gear.3mf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]
2026-06-16 add fc esc docs
2026-06-17 add user study
    [study2_results_tabulated.xlsx]
2026-07-14 Added the software to measure airflow to the orchestrator directory. See orchestrator/airflowsensor.
    [FlowElement_grip.f3d, Flow_element_grip.3mf, Rod_grip.3mf]
2026-09-01 Log Nano supply voltage with potentiometer data
2026-10-06 fix swarm manifest sample
2026-10-08 Add interactive orchestrator entry for estimator IMU calibration
2026-10-11 refactor: separate camera pose estimation
2026-10-20 Save local interaction missions, calibration workflows, and launcher updates
2026-10-29 Configure 0.3-second S-curve tail while retaining current no-coast mission
2026-11-12 Require tighter servo calibration and final swarm verification
2026-11-12 Persist verified calibration offsets and outcomes in swarm manifest
2026-11-12 Disable optional calibration verification sweeps by default
2026-11-14 Release Blender add-on 1.25.2 with body scaling and hinge alignment
